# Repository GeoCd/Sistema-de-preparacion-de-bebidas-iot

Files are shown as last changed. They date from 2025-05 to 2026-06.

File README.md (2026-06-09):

# SISTEMA SEMIAUTOMÁTICO DE PREPARACIÓN DE BEBIDAS CON LA COMBINACIÓN DE TRES INGREDIENTES UTILIZANDO TECNOLOGÍAS IoT

**Thesis Project | UPIITA - IPN | 2023-2025**

Automated beverage preparation system combining up to three ingredients per recipe. A NEMA stepper motor positions a dispensing platform across three stations; peristaltic pumps and solenoid valves dispense each ingredient with flow-sensor feedback. An Arduino Mega handles all hardware control and communicates over UART with a Raspberry Pi running a Flask web server, which exposes a user-facing ordering interface and an operator dashboard, accessible remotely via Cloudflare Tunnel.

---

## Architecture

```
User / Operator (Browser)
        |
   Cloudflare Tunnel
        |
   Raspberry Pi
   └── Flask (app.py)
       ├── Ordering frontend  (index.html)
       ├── Operator dashboard (dashboard.html)
       ├── Recipe registry    (recetas.py)
       ├── SQLite DB          (pedidos_locales.txt)
       └── Serial (UART / JSON)
               |
         Arduino Mega
         ├── Stepper driver TB6600  → Platform positioning (3 stations)
         ├── Peristaltic pumps x7   → Ingredient dispensing
         ├── Solenoid valves x7     → Flow control
         ├── Flow sensors x7        → Volume feedback (interrupt-driven)
         └── FSR-406                → Cup presence detection
```

---

## Hardware

| Component | Role |
|---|---|
| Raspberry Pi | Web server, order management, serial coordinator |
| Arduino Mega | Real-time hardware control |
| NEMA Stepper + TB6600 | Platform positioning across 3 dispensing stations |
| Peristaltic pumps x7 | Ingredient dispensing |
| Solenoid valves x7 | Flow control per ingredient |
| Flow sensors x7 | Pulse-based volume measurement |
| FSR-406 | Cup presence detection |

**Ingredients supported:** Mineral water, lemon juice, orange juice, natural syrup, gin, white tequila, white rum.

---

## Firmware

Written in C++ for Arduino Mega:

| File | Description |
|---|---|
| `Prue_Web_IoT_270625.ino` | Main entry point. Pin definitions, setup, serial loop |
| `prepBeb.ino` | Recipe lookup and sequential ingredient dispensing |
| `movNema.ino` | Stepper motor positioning between stations 1-3 |
| `valorDispensado.ino` | Interrupt-driven flow sensor pulse counting and volume control |
| `Externas.ino` | FSR cup detection, JSON error/confirmation responses, ingredient-to-pin mapping |
| `RecBebidas.ino` | Recipe registry (16 recipes) and lookup function |
| `IngBebidas.ino` | Ingredient definitions per recipe |
| `setupPins.ino` | GPIO configuration |
| `webSocket.ino` | Serial state reporting (placeholder, not active in production) |
| `ESTRUCTURAS.h` | `Ingrediente` and `Receta` struct definitions |

**Communication protocol:** Arduino receives JSON over UART (`{"Nombre": "MOJITO", "Cantidad": 1}`), executes the recipe, and responds with `{"ok": true}` or `{"error": "..."}`.

**Volume control:** Flow sensors are read via hardware interrupts. Dispensing stops when accumulated pulse count reaches the target volume (`mlPorPulso = 0.48 ml/pulse`), achieving a minimum dosing error of 5% across 40 validated test cycles.

---

## Web Application

| File | Description |
|---|---|
| `app.py` | Flask server, serial communication handler, order routing |
| `recetas.py` | Recipe registry mirrored from firmware, used for order validation |
| `logs.py` | Terminal message formatting |
| `pedidos_locales.txt` | SQLite order log |
| `templates/index.html` | Customer-facing ordering interface |
| `templates/dashboard.html` | Operator monitoring dashboard |
| `templates/info.html` | Beverage information page |

Remote access is handled via Cloudflare Tunnel, exposing the Flask server without opening additional ports.

---

## Recipes (16)

Non-alcoholic: Limonada, Naranjada, Virgin Margarita, Citrus Punch

Gin-based: Mojito, John Collins, Shady Grove

Tequila-based: Bulldog, Margarita, Tequila Sunrise, Agave Julep, Changuirongo, Alamo Splash

Rum-based: Boston Cooler, Suzie Taylor, Daiquiri

---

## Mechanical Design

Visualization STL files are located in `/mechanical-designs`.

---

## Gallery
 
| | |
|---|---|
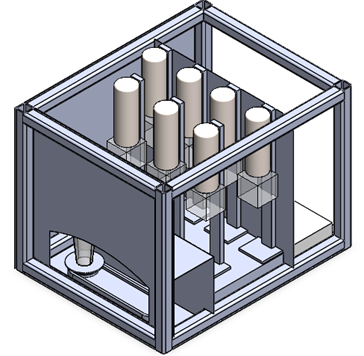
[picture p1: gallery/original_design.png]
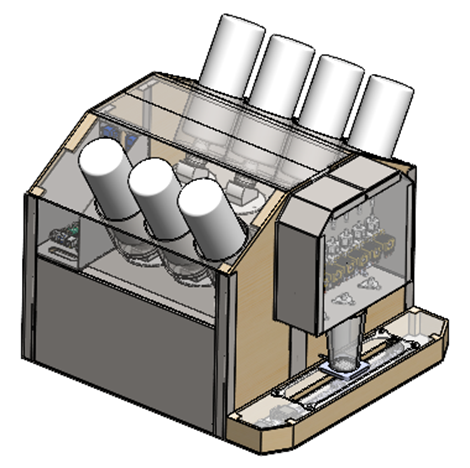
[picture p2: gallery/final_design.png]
| Original Design  | Final Design |
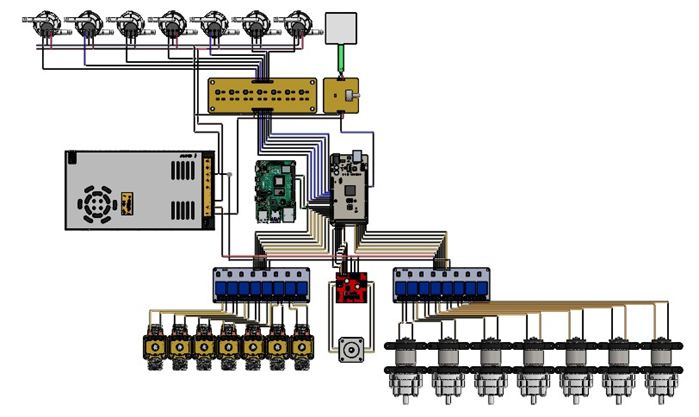
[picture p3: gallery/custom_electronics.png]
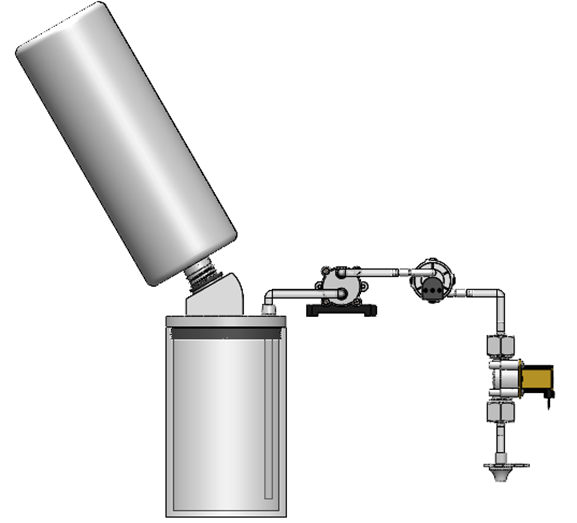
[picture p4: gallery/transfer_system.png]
| Custom Electronics  | Liquid Transfer System |
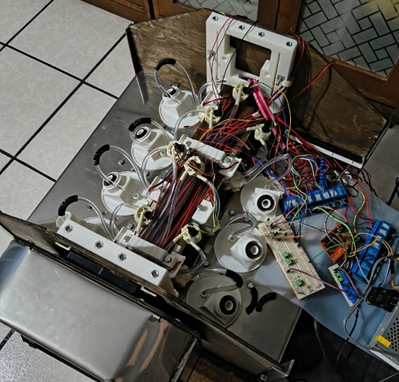
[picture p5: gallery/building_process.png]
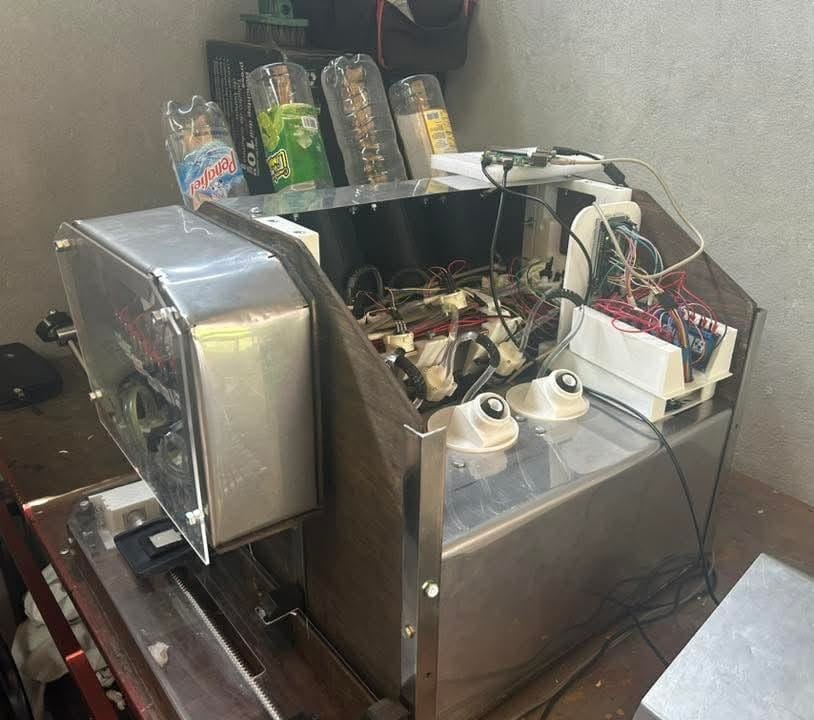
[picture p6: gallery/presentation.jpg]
| Building Process | Testing  |
 
---

## Authors

Jorge Andrés Conde Jaimes, Luis Alberto Peréz Sanchéz, Antonio Roldán Gabriel

UPIITA - Instituto Politécnico Nacional | 2023-2025

## Acknowledgements

Project advisor 1: Dr. Mata Machuca Juan Luis, UPIITA - IPN
Project advisor 2: M. Navarrete Manzanilla Niels Henrik, UPIITA - IPN

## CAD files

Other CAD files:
mechanical-designs/Estructural_covered.STL
mechanical-designs/Estructural_uncovered.STL

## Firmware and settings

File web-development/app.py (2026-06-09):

from flask import Flask, request, jsonify, render_template
from flask_socketio import SocketIO, emit
import serial.tools.list_ports
import serial, json, time, threading
from datetime import datetime
from queue import Queue
from recetas import RECETAS
from database import crear_tabla, guardar_pedido
from database import obtener_bebidas_mas_pedidas

app = Flask(__name__)
socketio = SocketIO(app, cors_allowed_origins="*")

crear_tabla()

cola_pedidos = Queue()
pedido_en_proceso = None
arduino = None

# Buscar puerto automáticamente
def conectar_serial():
    try:
        puertos_disponibles = list(serial.tools.list_ports.comports())
        print("Buscando puertos")
        for puerto in puertos_disponibles:
            nombre_puerto = puerto.device
            descripcion = puerto.description.lower()
            if "arduino" in descripcion or "usb" in descripcion or "ch340" in descripcion or "ttyACM" in nombre_puerto or "ttyUSB" in nombre_puerto:
                try:
                    ser = serial.Serial(nombre_puerto, 9600, timeout=1)
                    time.sleep(2)
                    print(f"Puerto serial conectado: {nombre_puerto}")
                    return ser
                except serial.SerialException as e:
                    print(f"No se pudo abrir el puerto {nombre_puerto}: {e}")
        print("No se encontró un Arduino conectado.")
        return None
    except Exception as e:
        print("Error al buscar puertos seriales:", e)
        return None

arduino = conectar_serial()

def finalizar_pedido_actual():
    global pedido_en_proceso
    if pedido_en_proceso:
        print("Pedido finalizado:", pedido_en_proceso.get("Nombre"))
        pedido_en_proceso = None
        cola_pedidos.task_done()

def procesar_pedidos():
    global pedido_en_proceso
    while True:
        if not pedido_en_proceso and not cola_pedidos.empty():
            pedido_en_proceso = cola_pedidos.get()
            print("Pedido listo para enviar cuando Arduino lo permita:", pedido_en_proceso.get("Nombre"))
        time.sleep(0.2)

def escuchar_confirmacion():
    global arduino, pedido_en_proceso
    while True:
        if pedido_en_proceso and arduino and arduino.is_open:
            try:
                arduino.write((json.dumps(pedido_en_proceso) + '\n').encode('utf-8'))
                print("Pedido enviado al Arduino:", pedido_en_proceso.get("Nombre"))
                time.sleep(0.2)
            except Exception as e:
                print("Error enviando al Arduino:", e)

            while True:
                try:
                    lineas = arduino.readline()
                    linea = lineas.decode('utf-8', errors='replace').strip()
                    print('Recibiendo:', repr(linea))
                    
                    if not linea:
                        continue
                    
                    # Validación de estructura JSON mínima
                    if not linea.startswith('{') or not linea.endswith('}'):
                        print("Línea descartada (estructura inválida):", repr(linea))
                        continue

                    try:
                        data = json.loads(linea)

                        if "ok" in data:
                            if data["ok"] is True:
                                print("Confirmación Arduino: OK recibido")
                                finalizar_pedido_actual()
                                break
                            else:
                                print("Pedido rechazado por Arduino:", data.get("error", "Motivo desconocido"))
                                finalizar_pedido_actual()
                                break

                    except json.JSONDecodeError:
                        print("JSON inválido recibido:", repr(linea))

                except Exception as e:
                    print("Error leyendo del Arduino:", e)
                    break
        time.sleep(0.2)
                    

def sensor_background_thread():
    global arduino, pedido_en_proceso
    while True:
        if pedido_en_proceso:
            time.sleep(3) 
            continue

        try:
            if arduino is None or not arduino.is_open:
                arduino = conectar_serial()
            if arduino and arduino.is_open:
                print("Consultando estado (WebSocket)")
                arduino.write(b'ESTADO\n')
                time.sleep(0.2)
                linea = arduino.readline().decode().strip()
                try:
                    if linea:
                        data = json.loads(linea)
                        print("Estado sensores:", data)
                        socketio.emit('arduino_data', data)
                except json.JSONDecodeError:
                    print("JSON inválido recibido (sensor):", linea)
        except Exception as e:
            print("Error en hilo de sensores:", e)
        time.sleep(3)

@app.route('/')
def index():
    return render_template('index.html')

@app.route('/dashboard')
def dashboard():
    return render_template('dashboard.html')

@app.route('/info')
def info():
    return render_template('info.html')

@app.route('/api/guardar_pedido', methods=['POST'])
def guardar_pedido_endpoint():
    try:
        data = request.get_json()
        timestamp = datetime.now().strftime("%d/%m/%Y %H:%M:%S")
        data["Hora"] = timestamp
        print("Pedido recibido:\n", json.dumps(data, indent=2, ensure_ascii=False))
        mesa = data.get("mesa", "N/A")
        for item in data["items"]:
            nombre = item["nombre"].upper()
            cantidad = item["cantidad"]
            precio = item.get("precio", 0.0)
            if nombre not in RECETAS:
                print(f"Receta no encontrada: {nombre}")
                continue
            receta = RECETAS[nombre]
            ingredientes_json = [{"Nombre": ing["Nombre"], "Cantidad_ml": ing["Cantidad_ml"]} for ing in receta]
            nombres_ingredientes = ", ".join([i["Nombre"] for i in ingredientes_json])
            paquete = { "Nombre": nombre, "Cantidad": cantidad }
            cola_pedidos.put(paquete)
            print(f"Pedido encolado: {nombre} x{cantidad}")
            guardar_pedido(timestamp, nombre, precio, cantidad, nombres_ingredientes, mesa)

        with open("pedidos_locales.txt", "a", encoding="utf-8") as f:
            f.write(json.dumps(data, ensure_ascii=False) + '\n')
            print("Pedido guardado localmente.")
        return jsonify({"status": "success", "message": "Pedido encolado correctamente."}), 200
    except Exception as e:
        print("Error al procesar el pedido:", e)
        return jsonify({"status": "error", "message": str(e)}), 400

@app.route('/api/ver_cola')
def ver_cola():
    return jsonify(list(cola_pedidos.queue))

@app.route('/api/pedido_actual', methods=['GET'])
def pedido_actual():
    global pedido_en_proceso
    if pedido_en_proceso:
        tiempo_por_ingrediente = 5
        cantidad = pedido_en_proceso.get("Cantidad", 1)
        tiempo_estimado = cantidad * tiempo_por_ingrediente
        return jsonify({
            "Nombre": pedido_en_proceso["Nombre"],
            "Cantidad": cantidad,
            "TiempoEstimado": tiempo_estimado
        })
    else:
        return jsonify({"status": "sin_pedido"}), 404

@app.route('/grafica-bebidas')
def grafica_bebidas():
    resultados = obtener_bebidas_mas_pedidas()
    formatted_data = [{"bebida": fila[0], "total": fila[1]} for fila in resultados]
    return jsonify(formatted_data)

@app.route('/api/tiempo_espera', methods=['GET'])
def tiempo_espera():
    tiempo_total = 0
    tiempo_por_ingrediente = 5
    for pedido in list(cola_pedidos.queue):
        cantidad = pedido.get("Cantidad", 1)
        tiempo_total += cantidad * tiempo_por_ingrediente
    minutos = tiempo_total // 60
    segundos = tiempo_total % 60
    return jsonify({"tiempo_segundos": tiempo_total, "formato": f"{minutos}:{segundos:02d}"})

if __name__ == '__main__':
    sensor_thread = threading.Thread(target=sensor_background_thread, daemon=True)
    sensor_thread.start()
    cola_thread = threading.Thread(target=procesar_pedidos, daemon=True)
    cola_thread.start()
    confirmacion_thread = threading.Thread(target=escuchar_confirmacion, daemon=True)
    confirmacion_thread.start()
    socketio.run(app, host='0.0.0.0', port=8080)

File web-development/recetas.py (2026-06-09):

# recetas.py
#----- Diccionario de recetas disponibles en el sistema -----#

RECETAS = { 
    "NARANJADA": [
        {"Nombre": "Agua", "Cantidad_ml": 150, "Estacion": 1},
        {"Nombre": "JugoN", "Cantidad_ml": 20, "Estacion": 1},
        {"Nombre": "Jarabe", "Cantidad_ml": 10, "Estacion": 2},
    ],
    "LIMONADA": [
        {"Nombre": "Agua", "Cantidad_ml": 150, "Estacion": 1},
        {"Nombre": "JugoL", "Cantidad_ml": 20, "Estacion": 1},
        {"Nombre": "Jarabe", "Cantidad_ml": 10, "Estacion": 2},
    ],
    "MOJITO": [
        {"Nombre": "Agua", "Cantidad_ml": 60, "Estacion": 1},
        {"Nombre": "JugoL", "Cantidad_ml": 25, "Estacion": 1},
        {"Nombre": "Ron", "Cantidad_ml": 60, "Estacion": 3},
    ],
    "JOHNCOLLINS": [
        {"Nombre": "JugoL", "Cantidad_ml": 2, "Estacion": 1},
        {"Nombre": "Jarabe", "Cantidad_ml": 2, "Estacion": 2},
        {"Nombre": "Ron Blanco", "Cantidad_ml": 1, "Estacion": 3}
    ],
    "SHADYGROVE": [
        {"Nombre": "Agua", "Cantidad_ml": 1, "Estacion": 1},
        {"Nombre": "Jugo L", "Cantidad_ml": 2, "Estacion": 1},
        {"Nombre": "Ron", "Cantidad_ml": 1, "Estacion": 3}
    ],
    "BULLDOG": [
        {"Nombre": "Agua", "Cantidad_ml": 1, "Estacion": 1},
        {"Nombre": "Jugo L", "Cantidad_ml": 2, "Estacion": 1},
        {"Nombre": "Ron Blanco", "Cantidad_ml": 1, "Estacion": 3}
    ],
    "BOSTONCOOLER": [
        {"Nombre": "Agua", "Cantidad_ml": 1, "Estacion": 1},
        {"Nombre": "Jugo L", "Cantidad_ml": 2, "Estacion": 1},
        {"Nombre": "Ron Blanco", "Cantidad_ml": 1, "Estacion": 3}
    ],
    "SUZIETAYLOR": [
        {"Nombre": "Agua", "Cantidad_ml": 1, "Estacion": 1},
        {"Nombre": "Jugo L", "Cantidad_ml": 2, "Estacion": 1},
        {"Nombre": "Ron Blanco", "Cantidad_ml": 1, "Estacion": 3}
    ],
    "ALAMOSPLASH": [
        {"Nombre": "Agua", "Cantidad_ml": 1, "Estacion": 1},
        {"Nombre": "Jugo L", "Cantidad_ml": 2, "Estacion": 1},
        {"Nombre": "Ron Blanco", "Cantidad_ml": 1, "Estacion": 3}
    ],
    "AGAVEJULEP": [
        {"Nombre": "Agua", "Cantidad_ml": 1, "Estacion": 1},
        {"Nombre": "Jugo L", "Cantidad_ml": 2, "Estacion": 1},
        {"Nombre": "Ron Blanco", "Cantidad_ml": 1, "Estacion": 3}
    ],
    "CHANGUIRONGO": [
        {"Nombre": "Agua", "Cantidad_ml": 1, "Estacion": 1},
        {"Nombre": "Jugo L", "Cantidad_ml": 2, "Estacion": 1},
        {"Nombre": "Ron Blanco", "Cantidad_ml": 1, "Estacion": 3}
    ],
    "MARGARITA": [
        {"Nombre": "Agua", "Cantidad_ml": 1, "Estacion": 1},
        {"Nombre": "Jugo L", "Cantidad_ml": 2, "Estacion": 1},
        {"Nombre": "Ron Blanco", "Cantidad_ml": 1, "Estacion": 3}
    ],
    "TEQUILASUNRISE": [
        {"Nombre": "Agua", "Cantidad_ml": 1, "Estacion": 1},
        {"Nombre": "Jarabe", "Cantidad_ml": 2, "Estacion": 2},
        {"Nombre": "Tequila", "Cantidad_ml": 1, "Estacion": 3}
    ],
    "DAIQUIRI": [
        {"Nombre": "JugoL", "Cantidad_ml": 1, "Estacion": 1},
        {"Nombre": "Jarabe", "Cantidad_ml": 2, "Estacion": 2},
        {"Nombre": "Ron", "Cantidad_ml": 1, "Estacion": 3}
    ],
    "CITRUSPUNCH": [
        {"Nombre": "JugoL", "Cantidad_ml": 1, "Estacion": 1},
        {"Nombre": "Jarabe", "Cantidad_ml": 2, "Estacion": 2},
        {"Nombre": "Ron", "Cantidad_ml": 1, "Estacion": 3}
    ]
}
#----- 14 recetas -----#

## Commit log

2025-05-10 Primer commit del proyecto Flask con frontend
    Primer carga de el proyecto desarrollado con python y arduino
2026-06-09 First commit for Thesis project documentation. Added models, gallery photos, web code and firmware for future collaborative development.
    [Estructural_covered.STL, Estructural_uncovered.STL]
